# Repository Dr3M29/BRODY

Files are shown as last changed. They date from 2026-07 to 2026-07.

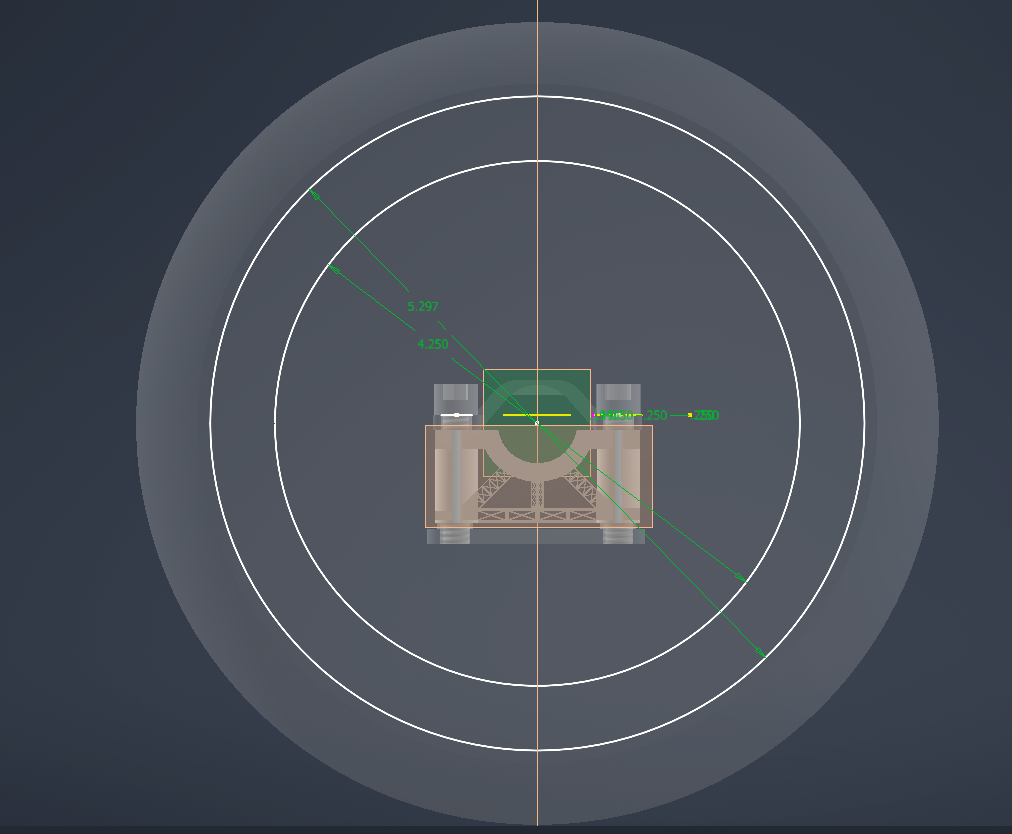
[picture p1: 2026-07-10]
images/wheel-hub.png

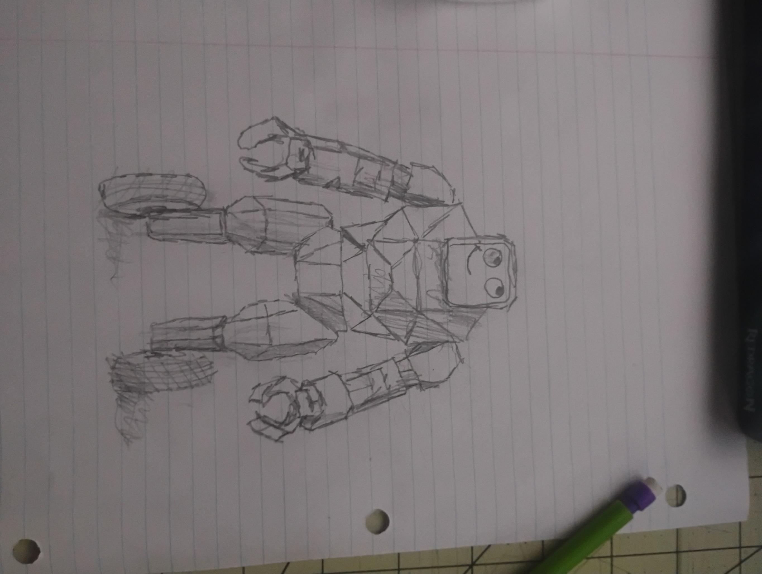
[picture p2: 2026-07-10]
images/sketch.jpg

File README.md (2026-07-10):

# BRODY

A robot I'm building out of a dead hoverboard, my e-bike battery, and an Arduino. Two wheels, LED face, posable arms, about 28" tall. Budget: whatever's in my pocket, which is not much.

## The story

My hoverboard died a while ago (battery gave out, everything else is fine). Turns out the two hub motors inside are strong enough to carry a person, and the motor boards can be reflashed with open source firmware so an Arduino can control them over serial. So instead of buying motor controllers ($60+) I'm hacking the boards the hoverboard already came with. Total spend so far on the motor side: an $8 debug probe.

The battery is borrowed from my Qlife e-bike - it slides onto a rail and locks with a key, so BRODY gets a slide-in battery too. It'll load through a hatch in his chest.

## Parts

**Free (salvaged from the hoverboard):**
- 2x brushless hub motors, 6.5" wheels
- 2x motor boards - MM32SPIN27PF chips, board marked YK189 / 210412
- charger, power button, charge port
- 2x LED light bars (turn signals, will reuse for accent lights)

**Borrowed:**
- 36V 10.4Ah e-bike battery (374Wh, 5.8 lbs) - shared with the bike

**Bought / buying:**
- CMSIS-DAP debug probe - $8
- header pins, spade connectors, wire, fuse, heat shrink - ~$15
- 8x8 LED matrix for the face - $5-10
- M3 heat set inserts - $10
- 4kg PETG - $40 (already have)

**Already had:** Arduino kit, soldering iron, 3D printer, calipers.

## How it goes together

Battery slides down a slant into the lower torso (head tilts up, chest hatch opens, battery drops in, rail lock holds it). Power comes off the pack's +/- blades with spade connectors, through a fuse, then splits left and right - one motor board lives in each leg, right above the wheel mount. The Arduino sits in the torso and talks to the boards over UART. Skinny signal wires run up, thick power wires run down, and the whole skeleton is PETG with a metal core in the hip beam since the battery weighs almost 6 pounds.

Stance is 16" wheel to wheel with the legs angled inward so he doesn't look like a table. Height is 28-30" for now - the spine is one straight segment on purpose so I can swap it for a longer one and make him 3 feet tall later.

The shell is separate from the skeleton. Skeleton takes all the weight, shell panels just screw or snap on so I can pull them off to get at the guts.

Top speed will be capped around 2 mph in software. The motors could do 8. They will not be doing 8 in my house.

## Firmware

The boards use MindMotion MM32SPIN27 chips (ARM Cortex-M0), which is the less common path - most guides assume STM32. Useful repos:

- https://github.com/RoboDurden/Hoverboard-Firmware-Hack-Gen2.x - the Gen2 split-board firmware project
- https://gitlab.com/ailife8881/Hoverboard-Firmware-Hack-Gen2.x-MM32 - MM32 version
- https://github.com/trondin/MM32SPIN05_Hoberboard_hack - SPIN05 port, close cousin, UART control works

Flashing is over SWD (3 wires) with a CMSIS-DAP probe and pyOCD. The chips ship read-protected so first contact needs a full erase. Two gotchas I know about going in: the board layout has to be matched against the repo before flashing (wrong pin map = dead MOSFETs), and the chip controls its own power latch, so you have to physically hold the power button the entire time you flash or the board shuts off mid-write.

## Progress

Done:
- figured out the hoverboard's problem (battery, not boards)
- identified the chips and found the programming + UART pads (labels are on the back of the board)
- found the battery's + and - blades
- picked materials and the overall design

Next up:
- multimeter check on the battery blades before ANY wiring happens
- solder headers onto the boards
- match the board layout, flash both boards
- spin the motors from the PC, then from the Arduino
- CAD the skeleton, print the hip beam and legs
- rolling chassis (with a caster - self balancing is a someday problem)
- LED face, head tilt servo, ultrasonic sensors
- arms (posable now, servos later)
- Raspberry Pi for talking and roaming, eventually

## Ground rules

Lithium batteries are the one part of this that can actually hurt you, so: no charging the old dead pack (it's getting recycled), nothing connects to the battery until a multimeter confirms the pinout, one wire cut at a time, fuse on the positive lead, and my dad's around for battery work.

---

CAD files and Arduino code will land here as they exist.

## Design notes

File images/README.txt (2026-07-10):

Drop your 5 screenshots in this folder with these exact names, and the site
will show them automatically (until then, simple placeholders show instead):

  sketch.jpg        <- the pencil sketch of Brody
  wheel-front.png   <- the round wheel, front view with the dimensions
  wheel-inside.png  <- the internal frame / motor mount inside the wheel
  wheel-hub.png     <- the drive assembly sitting in the wheel
  wheel-side.png    <- the side profile with the small bracket on the left

Tip: names are case-sensitive on GitHub. .png or .jpg both work if you match
the name in index.html.

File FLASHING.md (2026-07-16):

# Flashing BRODY's motor boards

Notes and status for reflashing the two hoverboard motor boards. Companion to the
firmware section in the [README](README.md).

## The board
- Chip: **MM32SPIN27PF** (ARM Cortex-M0, an MM32SPIN2X). Confirmed alive: CPUID = 0x410CC200.
- Board markings: H217776A / E472363 / JK-1 94V-0 / YK189, dated 2021-05.
- Two identical boards, one per wheel. Each has its own MM32 chip. Flash both, one at a time.

## Tools
- **Raspberry Pi Debug Probe** (CMSIS-DAP) over SWD.
- **pyOCD** (installed). Device pack installed: `MindMotion.MM32SPIN2x_DFP`
  (`pyocd pack install mm32spin27pf`).

## Wiring
SWD header pads on the board: **3.3V / SWCLK / SWDIO / GND**, plus a separate **nRST**
(reset) pad that's needed for the unlock step (below).

Plug the probe cable into the **"D" (SWD) port, NOT the "U" (UART) port.**
This cost a whole session of "No ACK". U is a serial port, it has no SWD on it.

| Probe wire | Board pad |
|---|---|
| orange | SWCLK |
| yellow | SWDIO |
| black  | GND |

For the actual flash, also find the **nRST** pad plus a jumper wire to touch it to GND.

## Powering it to flash
- **Do NOT** back-power the board from an external 3.3V (Arduino / programmer). The
  community warns this has killed boards. Fine for a quick read, not for writing.
- **Do** power from the ~36V battery (or a current-limited bench supply) and **hold the
  power button** the whole time, or the chip drops its power latch and switches off mid-write.

## Firmware (found 2026-07-16)
- Project: **RoboDurden Hoverboard-Firmware-Hack-Gen2.x** and its **MM32 fork**
  (SourceForge "hoverboard-hack-gen2-mm32", gitlab ailife8881). Supports MM32SPIN0X and
  **MM32SPIN2X** (your SPIN27 is a SPIN2X).
- **The safe way that protects the MOSFETs: the AutoDetect / PinFinder firmware.** You
  flash a special autodetect firmware first; it probes the board and reports the correct
  pin layout WITHOUT the wrong-pinmap risk. Then you flash the real firmware with the
  matching `#define LAYOUT x` in `Inc/config.h`.
  - Autodetect binary: **`HoverboardOutput.hex`** in the SourceForge `/autodetect` folder.
    Confirm it's built for SPIN2x/SPIN27 (or build from the source there) before flashing.
- Wrong LAYOUT can "shortcut the battery and kill the mosfets", so the autodetect step is
  the whole point: never guess the layout.

## Unlock + flash procedure (pyocd)
The chip ships read-protected; unlock it with a mass erase using the nRST trick:
1. Connect the board's **nRST pad to GND** with a jumper.
2. Run: `pyocd erase -t mm32spin27pf --chip`
3. The instant you see "Erasing chip...", **pull the nRST jumper off GND.**
4. Flash the autodetect firmware: `pyocd flash -t mm32spin27pf HoverboardOutput.hex`
5. Run it, read back the detected layout, then flash the final firmware (built with the
   matched LAYOUT) the same way: `pyocd flash -t mm32spin27pf yourfirmware.hex`

Do all of this on proper battery power, power button held.

## Status (2026-07-16)
- SWD connect to board #1 works (`pyocd reset -t cortex_m`, CPUID reads OK).
- Chip is **read-protected** (flash read fails, core read works), so it needs the unlock above.
- `-t mm32spin27pf` errored on its vendor debug sequence; likely fixed by the nRST unlock
  trick (the read-protected chip needs nRST grounded to let the programmer in).
- Not yet flashed. Board #2 not wired yet.

## What's still needed before flashing
1. Wire the **nRST** pad (a 5th connection).
2. Power from the **battery** (button held), not the Arduino 3.3V.
3. Confirm or build the **SPIN2x autodetect binary**.
4. Then: unlock, flash autodetect, read the layout, flash the final firmware.

## Commands that work today
```
pyocd list
pyocd reset -t cortex_m --frequency 500000
pyocd commander -t cortex_m -c "halt" -c "read32 0xe000ed00"
```

## Links
- RoboDurden main project: https://github.com/RoboDurden/Hoverboard-Firmware-Hack-Gen2.x
- MM32 fork (gitlab): https://gitlab.com/ailife8881/Hoverboard-Firmware-Hack-Gen2.x-MM32
- MM32 binaries (SourceForge): https://sourceforge.net/projects/hoverboard-hack-gen2-mm32/files/

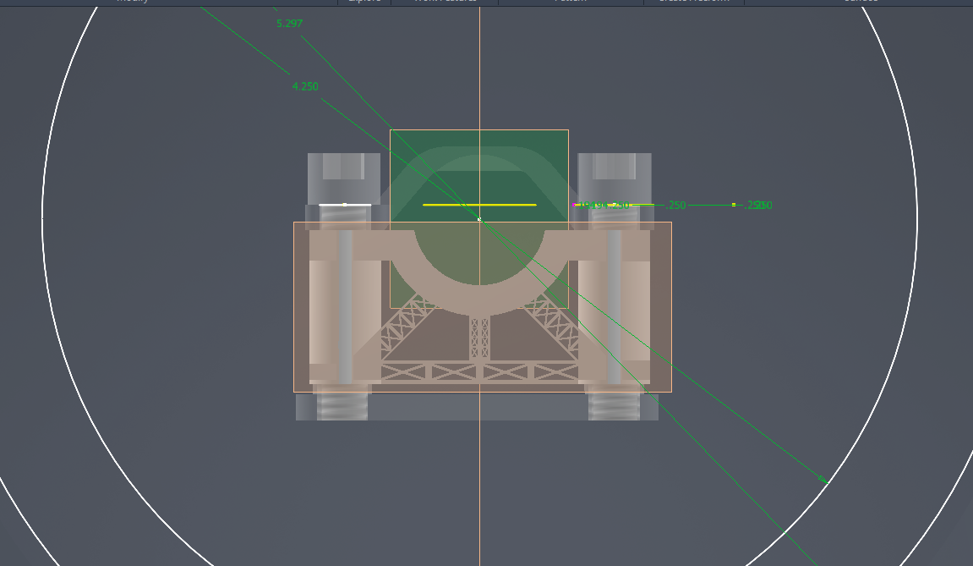
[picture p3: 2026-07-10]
images/wheel-inside.png

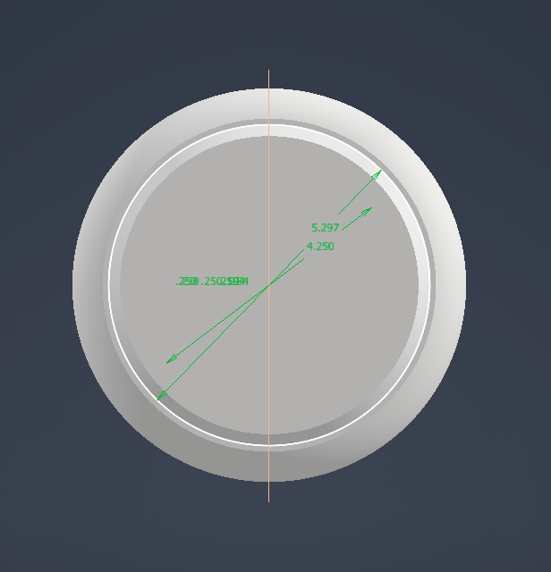
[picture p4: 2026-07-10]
images/wheel-front.png

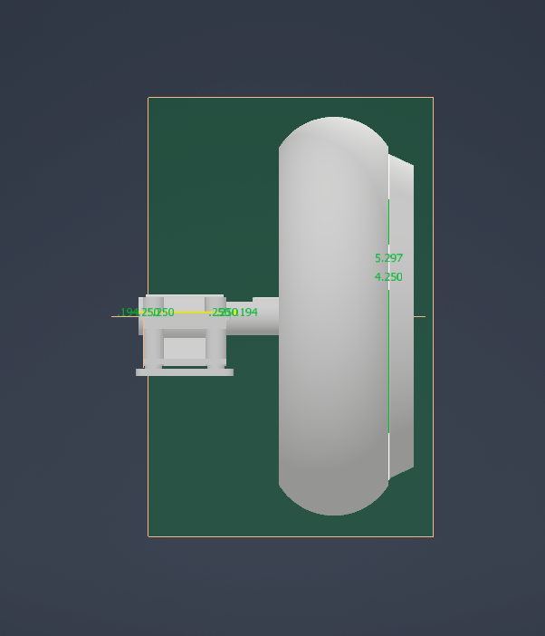
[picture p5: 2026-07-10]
images/wheel-side.png

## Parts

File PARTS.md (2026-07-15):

# BRODY — Full Parts List & Shopping Checklist

Companion to the [README](README.md). This is the detailed bill of materials — what's
salvaged, what's on order, and what still needs buying — grouped by subsystem. Prices are
rough USD.

**Status key:** ✅ have · 🟡 on order / buying · 🛒 still need · ⚪ optional

---

## The power tree (how it all connects)

```
36V e-bike battery  (~42V charged, 5.8 lb, key-lock rail)
        │
     [ 40A fuse ]   ← on the + lead, right at the pack
        │
        ├─ 36V ──→ motor board (L) ──→ hub motor (L)
        ├─ 36V ──→ motor board (R) ──→ hub motor (R)
        │
        └─ 36V ──→ buck converters  (MUST be rated for 42V+ input!)
                     ├─→ 5V  ──→ Raspberry Pi ──(USB)──→ Arduino
                     ├─→ 5V  ──→ speaker amp, sensors
                     └─→ 12V ──→ salvaged LED bars, LED face
```

\* Servos get their **own** 5V rail, not the Pi's — otherwise they brown out and reboot the Pi. (Moot now: no servos in the build, so there is no servo rail to worry about.)
Everything shares a **common ground**. High-voltage (36V) and logic (5V) stay separate; only
GND and signal wires cross between them.

---

## ✅ Salvaged / already have

| Item | Notes |
|---|---|
| 2× hub motors + 6.5" wheels | From the dead hoverboard. The "wheels." |
| 2× motor boards | MM32SPIN27PF chips, marked YK189 / 210412. These **are** the motor drivers. |
| 36V e-bike battery | 10.4Ah, 374Wh, 5.8 lb. Slides on a **key-lock rail — reuse that as the battery lock.** The slide-in dock is not coming, so tap the pack's + / - blades directly (meter first, fuse the + lead, dad present). |
| 2× LED light bars | Hoverboard turn signals → accent lights. 2-wire, single color (test at **12V**). |
| Monitor speaker | 4Ω 2W (salvaged stereo pair — only need **one** for a mono voice). |
| CMSIS-DAP debug probe | $8. Flashes the motor boards over SWD (3 wires). IN HAND now (a Raspberry Pi Debug Probe, which is CMSIS-DAP and works great with pyOCD). |
| Arduino kit | Real-time motor/servo/light control; talks to the Pi over USB. |
| Soldering iron, calipers, 3D printer | Already owned. |
| PETG (4kg) | Skeleton + shell panels. |

## 🟡 On order / already buying

| Item | ~Cost | Notes |
|---|---|---|
| Header pins, spade connectors, wire, fuse, heat shrink | $15 | Spades = **6.3mm / 0.25", yellow** (10–12 AWG). Fuse ~40A. Have now: cable/wire, heat shrink, fuses, and butt connectors. Still need header pins and spade/faston terminals (butt connectors splice wire-to-wire; the battery blades want spades). |
| 8×8 LED matrix (face) | $5–10 | Brody's face. |
| M3 heat-set inserts | $10 | Fastening skeleton + shell. |

## 🛒 Still need — Power distribution

| Item | ~Cost | Notes |
|---|---|---|
| Buck converter → **5V** | $6–12 | **Rated 12–80V input** (the e-bike / EV type). A basic LM2596 tops out at 40V and will **pop on a 42V pack** — don't use one. Get 5V @ **5A** for the Pi. HAVE ONE: got a 10-60V in / 5V 5A unit; its 60V input ceiling clears the ~42V pack. |
| Buck converter → **12V** | $5–8 | Same 12–80V input rating. Runs the salvaged LED bars + face. |
| Thick wire, 10–12 AWG (red + black) | $10 | Main battery / motor power runs. |
| Crimp tool (if not owned) | $15–20 | For clean, safe spade crimps. |

## 🛒 Still need — Brain & comms

| Item | ~Cost | Notes |
|---|---|---|
| Raspberry Pi 4 (4GB) or Pi 5 | $55–80 | Onboard brain for voice + roaming. HAVE ONE now (dad gave me a Pi); confirm the model so we can size its draw off the 5V buck. **Pi Zero 2 W (~$15)** is enough if the AI lives on a server and the Pi just relays commands + streams the camera. |
| microSD card, 32GB+ | $8 | The Pi's OS. |
| USB-C Pi power supply | $10 ⚪ | Handy for bench setup (on the robot it runs off the 5V buck). |
| USB cable (Arduino ↔ Pi) | — | Powers the Arduino **and** carries the commands. Likely already in your Arduino kit. |
| 1k resistor (UART level shift) | ~$0 | Single series resistor on the Arduino TX to board RX line (board TX to Arduino RX goes direct). Probably already in the kit. |
| IMU (MPU-6050) | $3-6 | BRODY's tilt sensor. The Arduino reads it 100+ times a second and runs the self-balance loop. REQUIRED now that he balances on two wheels, no caster. |

## 🛒 Still need — Voice

| Item | ~Cost | Notes |
|---|---|---|
| MAX98357A I2S amp | $6 | Cleanest amp for the Pi (no headphone jack needed). Drives the 4Ω speaker directly. |
| — or PAM8403 amp | $2 ⚪ | Analog alternative if you use a USB sound card / a Pi with a 3.5mm jack. |

*No DFPlayer needed — since the Pi is already onboard for the AI, it handles both the thinking
**and** the talking.*

## 🛒 Still need — Lights

| Item | ~Cost | Notes |
|---|---|---|
| Logic-level MOSFET (e.g. IRLZ44N) or MOSFET module | $1–3 | Lets the Arduino switch/dim the 12V LED bars — you can't drive them off a pin directly. |

## 🛒 Still need — Vision

| Item | ~Cost | Notes |
|---|---|---|
| USB webcam | $15 | **Main plan.** Plugs into the Pi; OpenCV reads it directly. Most include a **mic** — which Brody needs to listen / hold conversations anyway. Eyes + ears in one part. |
| — or Pi Camera Module | $15–25 ⚪ | Ribbon cable straight to the Pi's CSI port. Higher quality + lower latency, but no mic. |

*The old Android phone was going to be a WiFi IP-webcam, but it's water-damaged and dead. Don't
bother salvaging its camera sensor — phone cameras use proprietary MIPI connectors that won't
interface with a Pi.*

## 🛒 Still need — Motion & sensing

| Item | ~Cost | Notes |
|---|---|---|
| Caster wheel | $5–10 | NOT NEEDED. BRODY self-balances on two wheels (no caster), so there is no third contact point. |
| Servo — head tilt (SG90 or MG996R) | dropped | Not doing servos. Head is fixed/posable, arms are posable and friction-held (nyloc + nylon washers, bigger bolts at the shoulders). |
| Ultrasonic sensors (HC-SR04) | $2 ea | Obstacle detection for roaming. Grab 2–3. |
| PCA9685 16-ch servo driver | not needed | No servos in the build. |

## ⚪ Software (all free)

- **pyOCD** — flash the MM32 motor boards (repos + gotchas are in the README).
- **OpenCV** — camera / vision so Brody can "see."
- **Piper** or **espeak** (offline TTS), or a cloud voice — the actual talking.
- **Arduino IDE** — motor / servo / light firmware.

---

## Buy-this-first order (to keep momentum)

1. **Finish the motor test** — fuse, spades, wire, headers (on order). Flash the boards with the
   probe → spin the wheels from the PC, then from the Arduino. *(Battery multimeter check first —
   per the ground rules.)*
2. **Power distribution** — the two buck converters (5V + 12V). Now everything runs off the one pack.
3. **Lights** — MOSFET + confirm the LED bars' voltage (the 12V test). Wire up the 8×8 face.
4. **Brain** — Raspberry Pi + microSD. Get it talking to the Arduino over USB.
5. **Voice** — MAX98357A amp + the salvaged speaker. Brody's first words.
6. **Vision + roaming** — phone-as-camera (or a webcam), ultrasonic sensors, head servo.

## Rough budget for what's left

- **Essentials** (2 bucks, Pi, amp, MOSFET, caster, a servo, sensors, USB webcam, wire): **~$120–180**
- **Optional / backup** (webcam, crimp tool, extra servos): another **~$40–60**

---

*Companion to the [README](README.md), which has the story, the design, and the firmware details.
Update this as parts land.*

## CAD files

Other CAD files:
Brodyv2.iam
FastenerForLegFrame.ipt
OldVersions/BrodyLegToWheelConnecter.0002.ipt
OldVersions/Brodyv2.0005.iam
OldVersions/FastenerForLegFrame.0001.ipt
OldVersions/Wheel Bracket.0002.ipt
OldVersions/Wheel.0002.ipt
Wheel Bracket.ipt
Wheel Bracket_MIR.ipt
Wheel.ipt
WheelBracketConnector.ipt
WheelBracketScrew.ipt
WheelBracketScrew_MIR1.ipt
Wheel_MIR.ipt

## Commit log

2026-07-10 Add Brody milestone site and CAD parts
    Milestone #1: wheels and brackets. Includes a simple one-page site
    (index.html + images) alongside the Inventor parts and assemblies.
    [BrodyLegToWheelConnecter.0002.ipt, Brodyv2.0005.iam, Brodyv2.iam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]
2026-07-15 Update PARTS.md: buck acquired, no servos, resistor level-shift, no battery dock
2026-07-15 PARTS.md: no caster, add IMU for balancing, probe + Pi in hand
2026-07-16 Add FLASHING.md: SWD flashing setup, status, and the U-vs-D probe lesson
